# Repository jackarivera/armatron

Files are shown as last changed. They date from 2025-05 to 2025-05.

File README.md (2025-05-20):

# Armatron 7-DOF Robot Arm

## Project Overview
Armatron is an open-source 7-degree-of-freedom robotic arm project that combines hardware, software, and web-based control. This repository contains all the necessary files to build, program, and control your own Armatron robot arm.

## Repository Structure
```
.
├── armatron_software/     # Software implementation
│   ├── controls/         # C++ control system
│   ├── web/             # Web interface
├── CAD Files/           # CAD models and drawings
└── resources/           # Additional resources
```

## Hardware Requirements

### Electronics
- BeagleBone Black (BBB)
- 7x Fully Integrated BLDC Motors
- Armatron Electronics System (See BOM and Electronics CAD)

### Mechanical Parts
- 3D Printed Components (STL files and Fusion360 Project Provided)
- Bearings
- Fasteners
- Timing Belts

## Software Requirements
- WSL2 with Ubuntu (recommended)
- Python 3.x
- Node.js
- Git
- CMake
- Cross-compilation toolchain

## Getting Started

### 1. Hardware Assembly
1. Download the CAD files / Fusion 360 Project from the CAD files directory
2. Familiarize yourself with the mechanical structure of the project
3. Print or manufacture the structural pieces within the project (Recommended 3D Print Material: PA12 Nylon CF [Bambulabs PAHT-CF or similar])
4. Assemble mechanical pieces
5. Wire the motors. This is left up to you how you want to wire it. When I built armatron, I hand soldered a long wiring harness using the electrical raceway design I provided. This was extremely taxing and I recommend brainstorming new wiring methods that make it easier to assemble.

### 2. Software Setup
1. Clone this repository
2. Navigate to the software directory
3. Run the setup script:
   ```bash
   ./setup_dev.sh
   ```
4. The setup script should ideally set up everything for cross compilation and remote development. I recommend using WSL2 or a linux machine for this. This script is specifically for developing remotely and cross compiling with deployments. You can of course also just build both the C++ project and Web dashboard on whatever control computer you are using instead. I leave this up to you to decide.

### 3. Deployment - if remotely deploying
1. Configure your BBB's IP and credentials in the setup files
2. Run the deployment script:
   ```bash
   sudo ./deploy.sh
   ```

## CAD Files
The `CAD Files` directory contains:
- Complete Fusion 360 project file
- Individual component files in multiple formats - These aren't organized that great so I recommend pulling new STL files from the fusion project

## Disclaimer
While this project has been built up to an actual product that functions correctly and has a lot of potential, it does lack comprehensive documentation, assembly guides, and troubleshooting tips. I do apologize for this, however, I completed this project in my final semester of college at Purdue University. I am now transitioning into a full time position at SpaceX and do not have nearly enough time to smooth the rough edges of this project. I am releasing this fully open source to ensure that individuals, universities, and even companys have access to high performance robotics at an affordable cost. I welcome all contributors and am seeking people to help keep this project alive and prospering! If you are interested- please email me directly and we can set up a time to chat. Alternatively, if you are feeling ambitious, the best way to understand this project is to just dive in. Read the code, view the CAD, and gain a deep understanding of what I have set up so far. I believe the best engineers are made by working through the tough projects that have minimal documentation. While I would prefer to provide step-by-step manufacturing, assembly, and software documentation and tutorials- I just don't have the time right now to provide this. I apologize for this but I believe with the right support, this project can take off and help eager students and engineers around the world a great starting point for creating something awesome!

## Known bugs at release (IMPORTANT)-
Please note that this project is not free of bugs and ignoring some bugs or blindly running the software provided with this project can lead to catastrophic failures. The actuators used in this project are POWERFUL. Please proceed with extreme care and DO NOT ASSUME that everything will work out of the box.

Here is a list of known bugs at release:
- moveToJointPositon() in C++ controls (robot_interface.cpp)
    - DOES NOT PROPERLY HANDLE INTERUPPTING ACTIVE TRAJECTORIES. A trajectory currently must finish before calling moveToJointPosition again. Alternatively, you can call setHoldPosition to stop the trajectory and then move again. 

## Not implemented features yet
- Forward or Inverse Kinematics
- Cartesian Space Trajectory controls
- Dynamics Controls
- Open endpoints for trajectory streaming
- ROS2 Project
- Full URDF implementation - A partial implementation exists for the web visualization though. See the web/public/models directory

## Contributing
We welcome contributions! If you are interested in contributing to this project please contact me directly or open a pull request! I am currently working with Rover Robotics (https://roverrobotics.com/) to help continue supporting this project.

## License
This project uses a slightly modified MIT license. The only modifications go to include ALL files included in this repository including CAD, BOM, Documentation, etc instead of just software.

## Support
- Create an issue in the repository
- Join our community forum (link to be added)

## Acknowledgments
- Created by Jack Rivera as a passion project during my final semester at Purdue University. Shoutout Professor Hyun, Professor Sundaram, and Professor Pare for inspiring me and supporting throughout the development.

- Special thanks to...
- Inspired by...

## Roadmap
- [ ] Add detailed manufacturing instructions
- [ ] Add detailed assembly instructions
- [ ] Add detailed software development instructions
- [ ] Create video tutorials
- [ ] Expand simulation capabilities
- [ ] Implement additional control modes (Kinematics, Dynamics, Cartesian Space, Energy Based, State Space, etc.)
- [ ] Add support for different end effectors 
- [ ] Expand web dashboard
- [ ] Add ROS2 support

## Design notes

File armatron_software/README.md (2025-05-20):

# Armatron 7-DOF Robot Arm Software

## Project Overview
Armatron is a 7-degree-of-freedom robotic arm project, featuring a web-based control interface and real-time control system. The robot is controlled via a BeagleBone Black (BBB) running Debian Linux, providing a robust and flexible platform for robotics development.

### Key Features
- 7-DOF robotic arm control
- Real-time control daemon
- Web-based user interface
- Cross-compilation support for ARM architecture
- Automated deployment system
- Systemd service management

## Project Structure
```
armatron_software/
├── controls/                 # C++ control system
│   ├── src/                 # Source files
│   ├── include/             # Header files
│   └── build/               # Build directory
├── web/                     # Web interface
│   ├── public/              # Static files
│   ├── src/                 # Source files
│   └── node_modules/        # Node.js dependencies
├── deploy/                  # Deployment files
├── setup_dev.sh            # Development environment setup
├── deploy.sh               # Deployment script
└── toolchain.cmake         # CMake toolchain configuration
```

## Development Environment Setup

### Prerequisites
- WSL2 with Ubuntu (recommended)
- Python 3.x
- Node.js
- Git
- CMake
- Cross-compilation toolchain

### Initial Setup
1. Clone the repository:
```bash
git clone <repository-url>
cd armatron_software
```

2. Run the setup script:
```bash
./setup_dev.sh
```

This will:
- Install required packages
- Set up cross-compilation toolchain
- Create Python virtual environment
- Generate deployment scripts
- Configure CMake toolchain

### Configuration
Edit the following files to set your BBB's IP and credentials:
1. `setup_dev.sh`
2. `deploy.sh`

## Deployment

### Regular Deployment
For normal development and updates:
```bash
sudo ./deploy.sh
```

This will:
- Build the project
- Deploy files to BBB
- Preserve node_modules
- Restart services

### Initial Setup on BBB
For first-time setup or when BBB environment needs reinitialization:
```bash
sudo ./deploy.sh --setup
```

This will:
- Run all regular deployment steps
- Execute setup_bbb.sh on the BBB
- Install system dependencies

### Node Modules Management
Node modules are automatically checked and only installed if missing or invalid. No need to manually manage them.

## Service Management
The system uses two systemd services:
- `armatron-control`: Real-time control daemon
- `armatron-web`: Web interface server

Services are automatically managed during deployment.

## Development Workflow
1. Make changes to source code
2. Run `sudo ./deploy.sh`
3. Changes are automatically deployed and services are restarted

## Troubleshooting
- If services fail to start, check the logs:
  ```bash
  sudo journalctl -u armatron-control
  sudo journalctl -u armatron-web
  ```
- If node modules are missing, the deployment script will automatically install them
- For permission issues, ensure you're running the deploy script with sudo

## Notes
- The deployment script preserves node_modules to speed up deployments
- Sudo password is automatically handled for BBB commands
- The web interface communicates with the control daemon via Unix domain socket
- Cross-compilation is configured for ARM architecture

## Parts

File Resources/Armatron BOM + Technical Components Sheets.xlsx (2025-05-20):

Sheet: BOM (Motors)
Armatron 7 BOM
Total Cost (Pre-tax and Fees): $1501.20
Item # | Description | Vendor | Part Number | Qty | Cost | Link to Where to Purchase | AliExpress
1 | MG8015-9 Duo 2 V2 - 14-28Nm 177RPM | smc-powers | MG8015-9 | 2 | $263.00 | MG8015-9 (http://shop.smc-powers.com/MG8015-9-Duo-CAN.html) | MG8015E-i9 (https://www.aliexpress.us/item/3256807777004232.html)
2 | MG8008-9 Duo V3 - 10-20Nm 178RPM | smc-powers | MG8008-9 | 2 | $237.80 | MG8008-9 (http://shop.smc-powers.com/MG8008-9-Duo-CAN.html) | MG8016-i6v2 (https://www.alibaba.com/product-detail/MG8016-i6v2-RMD-X8-Brushless-bldc_1600372824820.html)
3 | MG4010-10 Duo V3 - 2.5-4.5Nm 260RPM | smc-powers | MG4010-10 | 1 | $168.00 | MG4010-10 (http://shop.smc-powers.com/MG4010-10-Duo-CAN.html)
4 | MG4005-10 - 1-2.5Nm 253RPM | smc-powers | MG4005-10 | 2 | $165.80 | MG4005-10 (http://shop.smc-powers.com/MG4005-Motor-CAN)

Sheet: BOM (Controls + Electronics Enc
Armatron 7 BOM
Total Cost: $987.77
Item # | Description | Vendor | Part Number | Qty | Cost | Link to Where to Purchase | AliExpress
1 | Beaglebone Black | Digikey | RPI5 | 1 | $53.77 | Digikey - BBB (https://www.digikey.com/en/products/detail/beagleboard-by-seeed-studio/102110420/12719590)
2 | Beaglebone Power Cape | Digikey | PWRCPE | 1 | $40.00 | Digikey - PWRCPE (https://www.digikey.com/en/products/detail/ghi-electronics-llc/PWRCPE-BBBCAPE/8567321)
3 | Beaglebone Comms Cape | Digikey | COMCPE | 1 | $40.00 | Digikey - COMCPE (https://www.digikey.com/en/products/detail/ghi-electronics-llc/COMCPE-BBBCAPE/8567318)
4 | Meanwell RSP-2000w-48v Power Supply | Digikey | RSP-2000-48 | 1 | $500.00 | Digikey - MWRSP (https://www.digikey.com/en/products/detail/mean-well-usa-inc/RSP-2000-48/7706318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)
5 | Meanwell 24v Power Supply - 24V 15A 360W | Owned (24v 15A Meanwell) | LRS-350-24 | 1 | $0.00 | Digikey - MWLRS (https://www.digikey.com/en/products/detail/mean-well-usa-inc/LRS-350-24/7705034)
6 | 10A 1P Circuit Breaker | RS | 2907566 | 1 | $20.00 | https://us.rs-online.com/product/phoenix-contact/2907566/70903605/
7 | 20A 1P Circuit Breaker | RS | 2907573 | 1 | $20.00 | https://us.rs-online.com/product/phoenix-contact/2907573/70903610/
8 | MakerBeam XL Kit | Amazon | MakerBeamXL | 1 | $200.00 | https://www.amazon.com/MakerBeam-XL-anodized-including-brackets/dp/B06XHXJSVL
9 | Parallel XT90s | Amazon | LINSYRC | 2 | $9.00 | https://www.amazon.com/LinsyRC-Parallel-Connector-Quadcopters-Multirotors/dp/B093GL6TPW
10 | XT90s Male + Females | Amazon | AMASS | 2 | $13.00 | https://www.amazon.com/XT90-S-Connector-Anti-Spark-Battery-Charger/dp/B08P5N29RK
 | Terminal Blocks Below
11 | Phoenix Contact 3212934 Feed-througterm block Push-in conn AWG:20-8 W:8.2mm 42.2mm gray NS35/7 5 NS35/15 | RS | 3212934 | 6 | $6.00 | https://us.rs-online.com/product/phoenix-contact/3212934/70925206/?referrer=search
12 | Phoenix Contact 3212950 Terminal Block Ground Modular Push-In PT 6-QUATTRO-PE PT Series | RS | 3212950 | 2 | $12.00 | https://us.rs-online.com/product/phoenix-contact/3212950/70378433/?keyword=3212950
13 | Phoenix Contact End Cover PT 6-QUATTRO | RS | 3212963 | 2 | $1.00 | https://us.rs-online.com/product/phoenix-contact/3212963/70254907/?referrer=search
14 | Phoenix Contact End Stop Din Rail | RS | 800886 | 4 | $2.00 | https://us.rs-online.com/product/phoenix-contact/0800886/70169101/?referrer=search
15
16
17
18
19
20
21
22
23
24
25
26
27
28
29
30
31
32
33
34
35
36
37
38
39
40
41
42
43
44
45
46
47
48
49
50
51
52
53
54
55
56
57

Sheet: BOM (Hardware)
Armatron 7 BOM
Total Cost: $44.50
Item # | Description | Vendor | Part Number | Qty | Cost | Link to Where to Purchase
1 | 6656K196 - Ultra Thin Ball Bearing (SHOULDER BEARING) | McMaster | 6656K196 | 1 | $10.74 | 6656K196 (https://www.mcmaster.com/6656K196/)
2 | 6656K201 - Ultra Thin Ball Bearing (WRIST BEARINGS) | McMaster | 6656K201 | 2 | $16.88 | 6656K201 (https://www.mcmaster.com/catalog/131/1431/6656K201)
3 | RS_12-8-3.5_747-800 (Differential Pignon Bearings) |  |  | 4
4 | 123R_14-8-4_SMR148_2RS_ZEN (Differential Main Axle Bearings) |  |  | 2
5 | Xl Series Timing Belt, Trade No. 140xl025 (https://www.mcmaster.com/catalog/6484K124)
 | Timing Belt, Xl Series, Trade Number 96xl025, 1/4" Wide (https://www.mcmaster.com/catalog/6484K2)

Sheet: Motor Torque Comparison
Item # | Description | Type | Vendor | Part Number | Rated Torque (Nm) | Max Torque (Nm) | 2:1 Gearbox | 2:1 Gearbox
1 | MG8015-9 Duo 2 V2 - 14-28Nm 177RPM | Motor | smc-powers | MG8015-9 | 14.00 | 28.00 | N/A | N/A
2 | MG8008-9 Duo V3 - 10-20Nm 178RPM | Motor | smc-powers | MG8008-9 | 10.00 | 20.00 | N/A | N/A
3 | MG4010-10 Duo V3 - 2.5-4.5Nm 260RPM | Motor | smc-powers | MG4010-10 | 2.50 | 4.50 | 5 | 9
4 | MG4005-10 - 1-2.5Nm 253RPM | Motor | smc-powers | MG4005-10 | 1.00 | 2.50 | 2 | 5

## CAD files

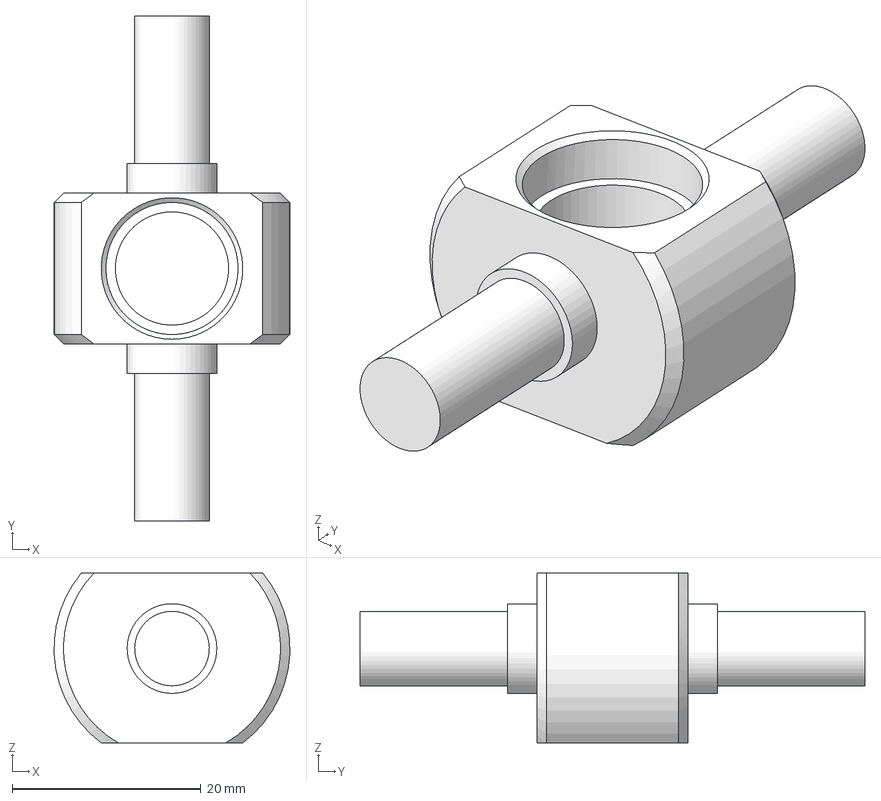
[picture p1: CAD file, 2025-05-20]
CAD Files/Differential Prints/main_axle.step
25.0 x 53.5 x 18.0 mm

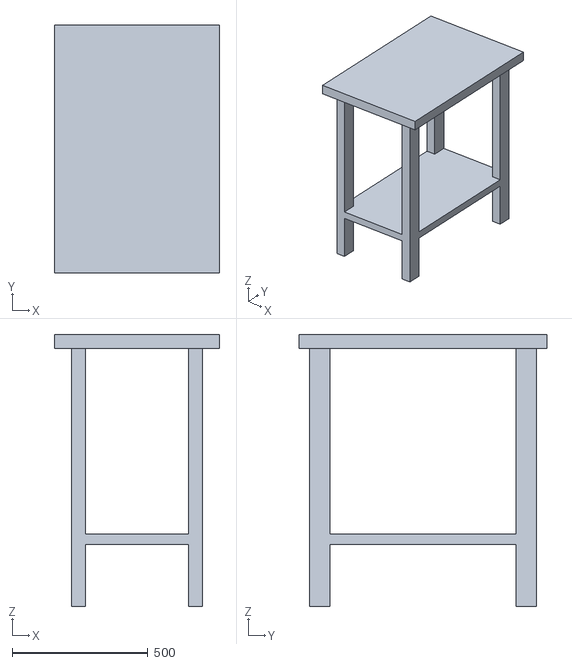
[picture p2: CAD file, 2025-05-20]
armatron_software/web/dist/models/urdf/meshes/demo_table.stl
609.6 x 914.4 x 1003.3

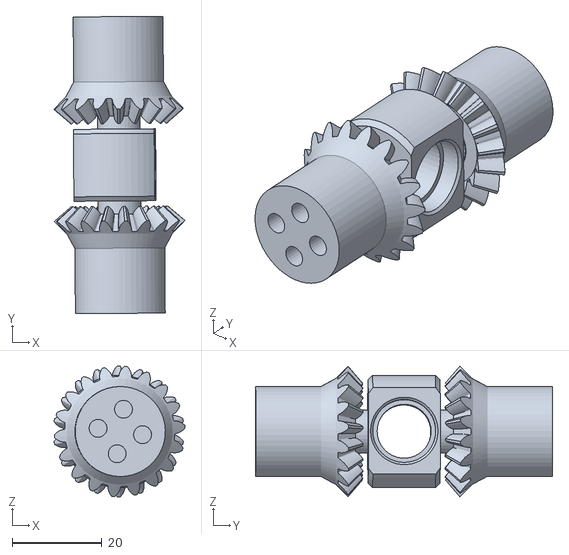
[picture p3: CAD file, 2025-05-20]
armatron_software/web/public/models/urdf/meshes/7_diff_crossbar_link.stl
29.1 x 66.2 x 29.1

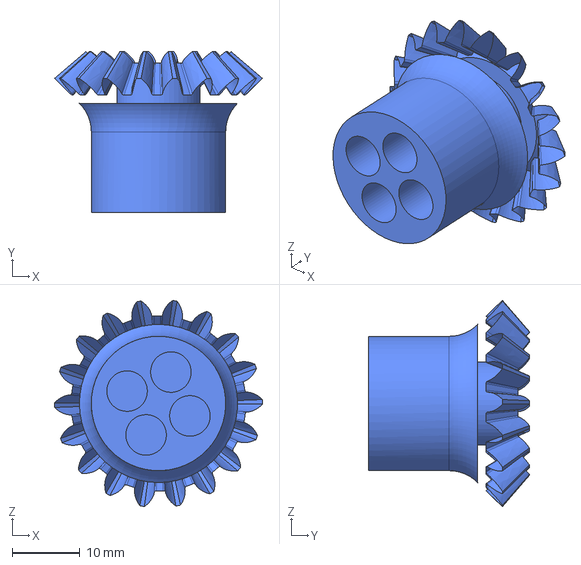
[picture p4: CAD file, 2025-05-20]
CAD Files/Differential Prints/pignon_ab.step
30.8 x 23.8 x 30.5 mm

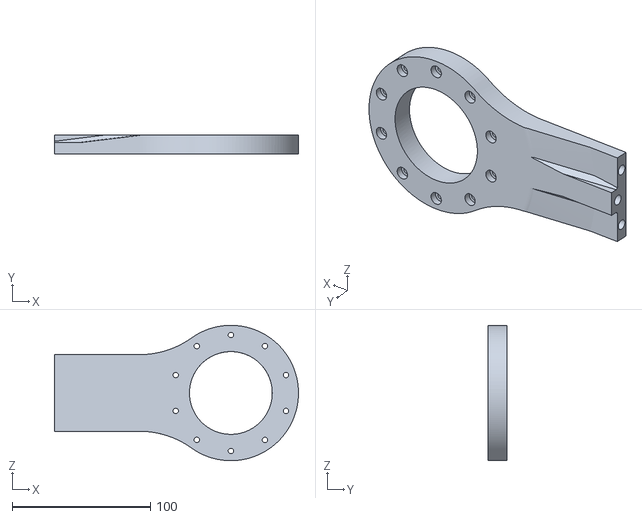
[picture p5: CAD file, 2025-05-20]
CAD Files/Elbow Prints/armatron_7 v125.stl
176.8 x 13.5 x 98.1

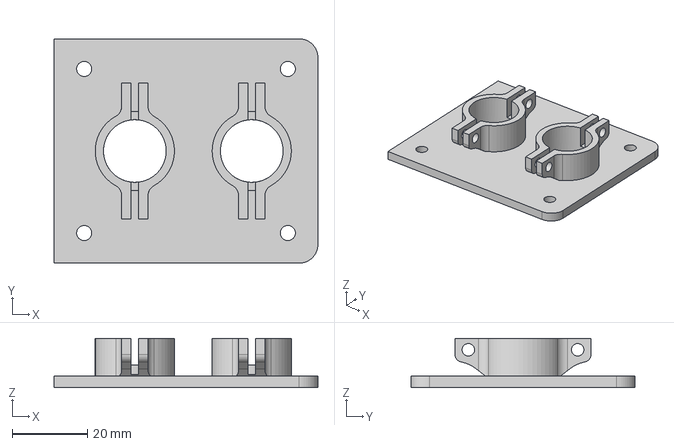
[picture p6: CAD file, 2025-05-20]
CAD Files/Electrical Raceway Prints/armatron_7 v181.step
70.0 x 59.5 x 13.0 mm

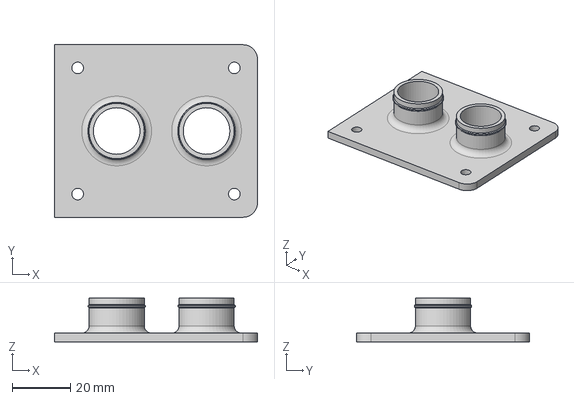
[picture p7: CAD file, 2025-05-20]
CAD Files/Electrical Raceway Prints/Joint 1/Joint_1_Lid.step
70.0 x 59.5 x 15.0 mm

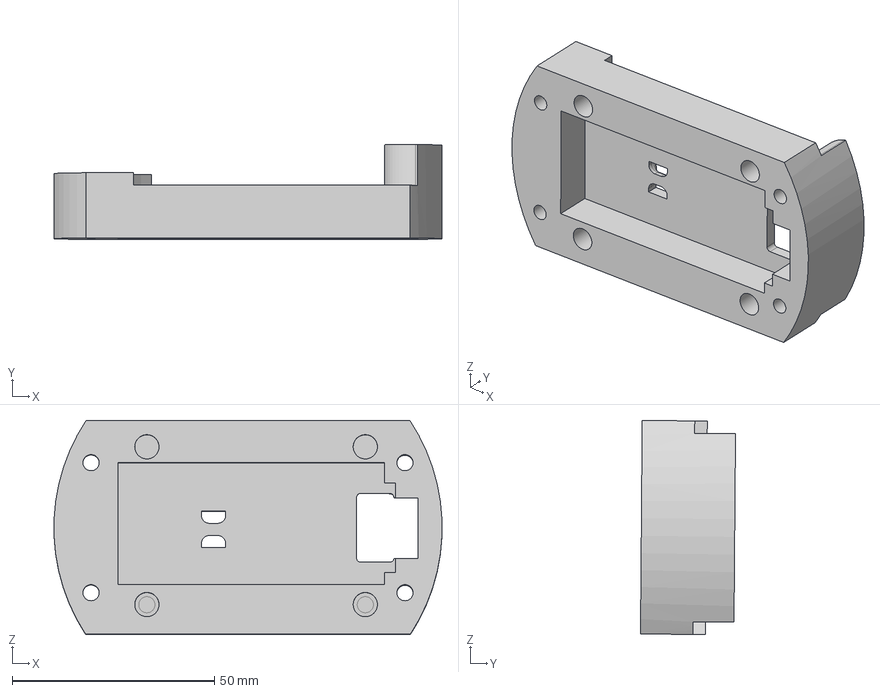
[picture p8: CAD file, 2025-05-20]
CAD Files/Electrical Raceway Prints/Joint 2/Joint_2_Base.step
95.9 x 23.5 x 52.9 mm

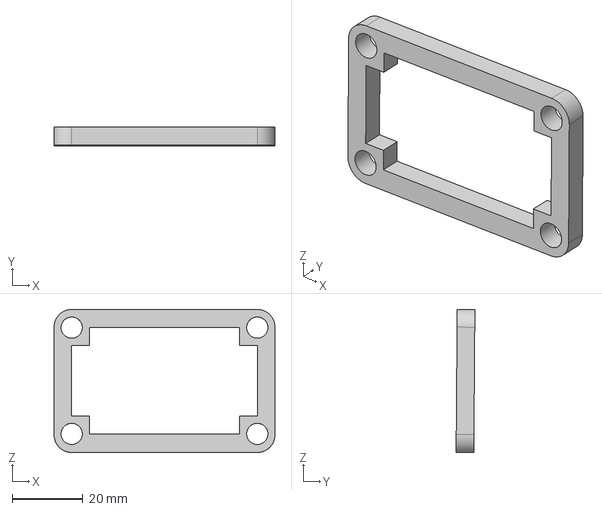
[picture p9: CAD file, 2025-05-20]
CAD Files/Electrical Raceway Prints/Joint 3/Joint_3_Spacer.step
62.4 x 5.32 x 40.4 mm

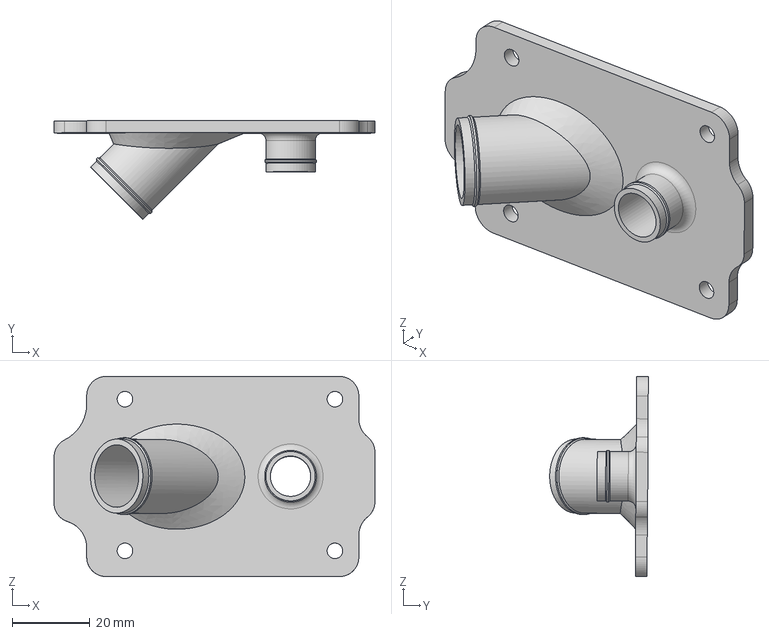
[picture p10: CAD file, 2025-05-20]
CAD Files/Electrical Raceway Prints/Joint 4/Joint_4_lid.step
82.6 x 25.4 x 51.5 mm

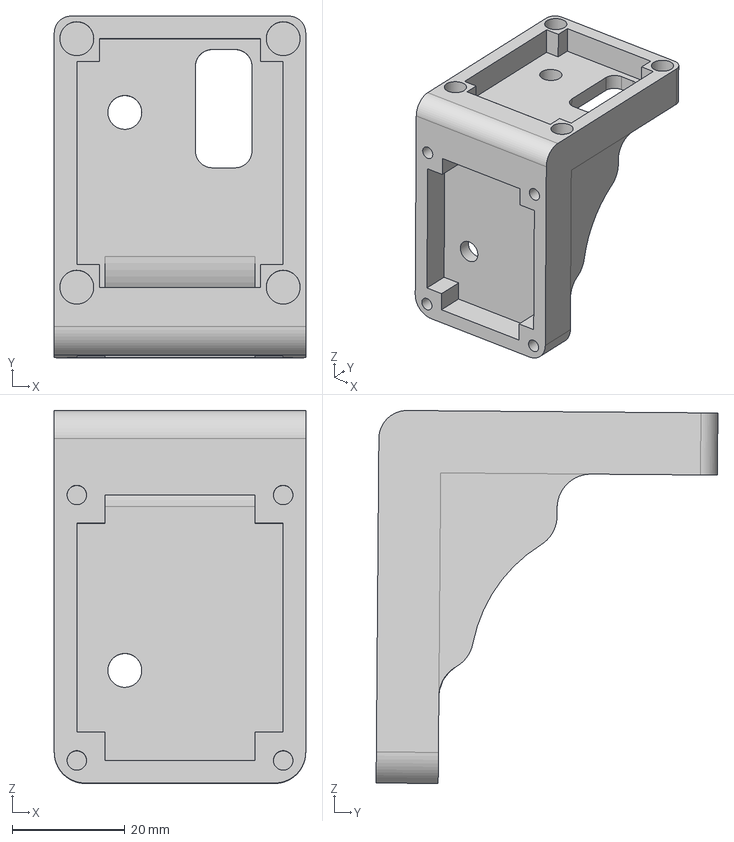
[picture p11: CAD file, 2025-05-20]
CAD Files/Electrical Raceway Prints/Joint 5/joint_5_base.step
44.5 x 60.5 x 66.0 mm

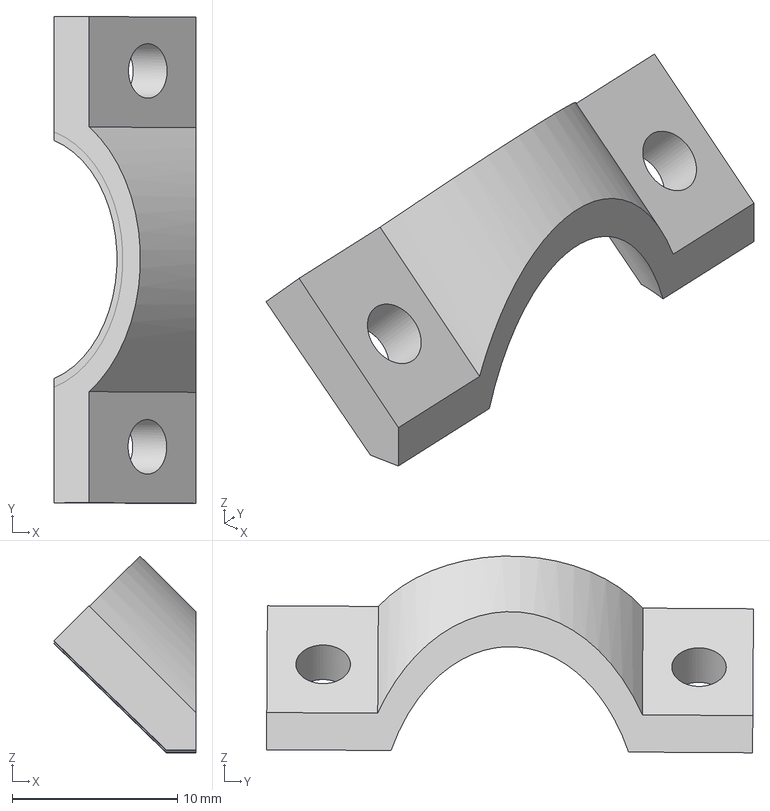
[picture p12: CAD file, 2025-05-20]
CAD Files/Electrical Raceway Prints/Joint 6/diff_clamp.step
8.58 x 29.5 x 11.9 mm

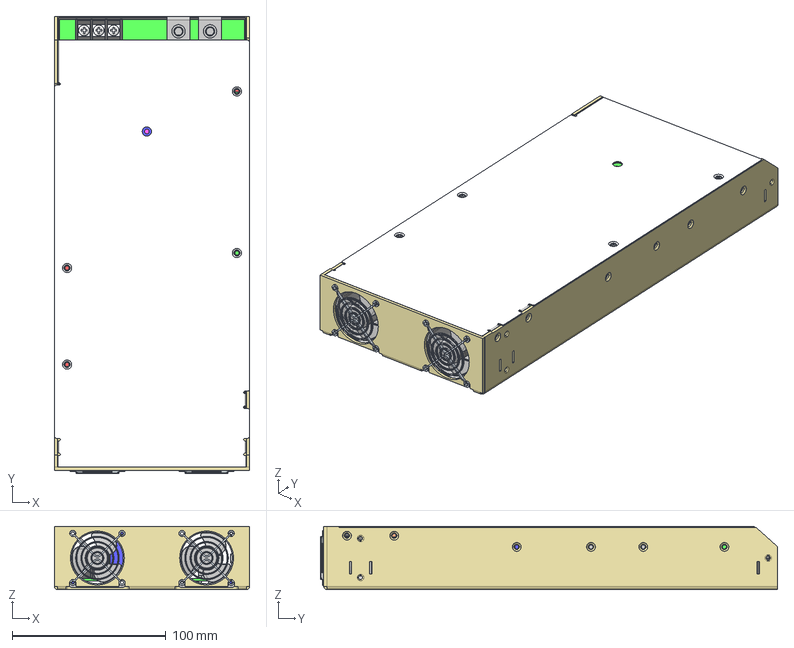
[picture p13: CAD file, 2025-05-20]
CAD Files/Electronics CAD/RSP-2000..stp
127.0 x 297.1 x 41.0 mm
nt x 4
p3.1 x 2
ºÝ¤l
pcb2
M3
VR.1
FAN x 4
fan_a x 4
pin.1 x 6
p3 x 2
pin
hs123
ff.1.1.1.1.1 x 3
CASE
M3-10LÁ³¬W.1.1.1.1.3 x 5
PCB-2
ºÝ¤l®y¤½W
MOS15.5x10.1.1.1.1.1.1.1.1.1.1.1.1.1 x 18
©T©w¤ù1 x 3
HHJ x 2
cu2
mylr
952¤W»\
pcb
HS3
p1.2 x 2

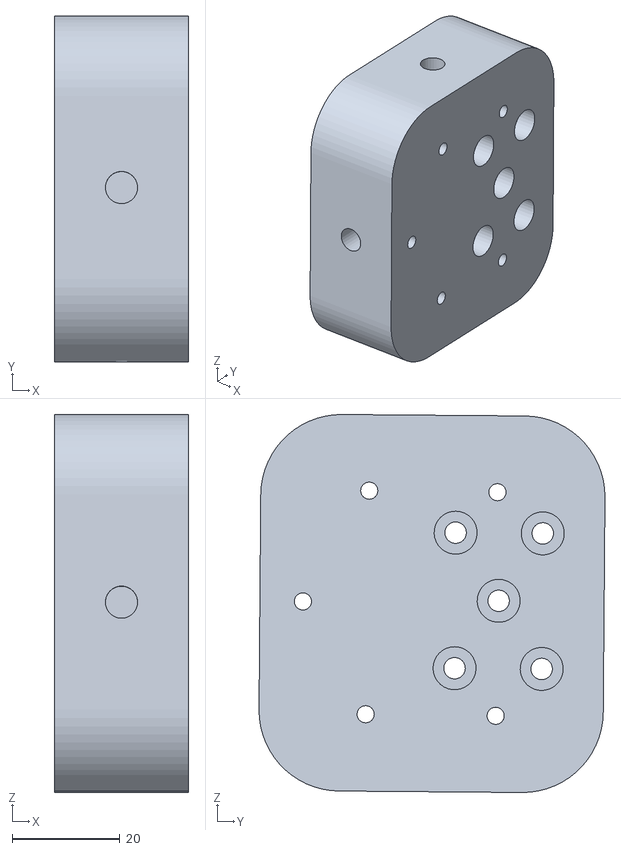
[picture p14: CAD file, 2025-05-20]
CAD Files/Forearm Prints/arm_to_motor_p1_nylon_toleranced.stl
25.0 x 64.3 x 70.3

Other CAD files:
CAD Files/Shoulder Prints/shoulder_faceplate.step
CAD Files/Test Mounts/force_gauge_mount.3mf
CAD Files/torque_test_stand v1 Bambu.3mf
CAD Files/Wrist Prints/divider.step
CAD Files/Differential Prints/pulley_diff.step
CAD Files/Elbow Prints/base_stand_p1_nylon.3mf
CAD Files/Elbow Prints/elbow_bambu_project.3mf
CAD Files/Elbow Prints/mount_p1_nylon_toleranced.stl
CAD Files/Electrical Raceway Prints/Joint 1/Joint_1_Base.step
CAD Files/Electrical Raceway Prints/Joint 1/Joint_1_Spacer.step
CAD Files/Electrical Raceway Prints/Joint 2/Joint_2_Clamp.step
CAD Files/Electrical Raceway Prints/Joint 2/Joint_2_Lid.step
CAD Files/Electrical Raceway Prints/Joint 2/Joint_2_Spacer.step
CAD Files/Electrical Raceway Prints/Joint 3/Joint_3_Base.step
CAD Files/Electrical Raceway Prints/Joint 3/Joint_3_Lid.step
CAD Files/Electrical Raceway Prints/Joint 3/Joint_3_clamp.step
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

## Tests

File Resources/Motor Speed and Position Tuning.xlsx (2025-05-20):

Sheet: MG8015 | Joint 1
Lever Arm Length | 0.047205
Torque Current Value (-2048-2048) | Force #1 | Force #2 | Force #3 | Avg Force (N) | Avg Torque (Nm) | Expected Torque (Nm)
50 | 24 | 23 | 23.2 | 23.4 | 1.104597 | 1.2
75 | 34.7 | 36 | 36.7 | 35.8 | 1.689939 | 1.705
100 | 48.8 | 48.6 | 48.8 | 48.73333333 | 2.300457 | 2.21
125 | 56.8 | 56.2 | 61.4 | 58.13333333 | 2.744184 | 2.715
150 | 67 | 68.5 | 68.7 | 68.06666667 | 3.213087 | 3.22
175 | 80 | 80.5 | 79.9 | 80.13333333 | 3.782694 | 3.725
200 | 89 | 90 | 89.7 | 89.56666667 | 4.2279945 | 4.23
225 | 98 | 98.6 |  | 98.3 | 4.6402515 | 4.735
250 |  |  |  | #DIV/0! | #DIV/0! | 5.24
275 |  |  |  | #DIV/0! | #DIV/0! | 5.745
300 |  |  |  | #DIV/0! | #DIV/0! | 6.25
325 |  |  |  | #DIV/0! | #DIV/0! | 6.755
350 |  |  |  | #DIV/0! | #DIV/0! | 7.26
375 |  |  |  | #DIV/0! | #DIV/0! | 7.765
400 |  |  |  | #DIV/0! | #DIV/0! | 8.27
425 |  |  |  | #DIV/0! | #DIV/0! | 8.775
450 |  |  |  | #DIV/0! | #DIV/0! | 9.28
475 |  |  |  | #DIV/0! | #DIV/0! | 9.785
500 |  |  |  | #DIV/0! | #DIV/0! | 10.29
525 |  |  |  |  |  | 10.795
550 |  |  |  |  |  | 11.3
575 |  |  |  |  |  | 11.805
600 |  |  |  |  |  | 12.31
625 |  |  |  |  |  | 12.815
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

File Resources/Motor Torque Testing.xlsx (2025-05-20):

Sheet: MG8015 | Joint 1
Lever Arm Length | 0.047205
Torque Current Value (-2048-2048) | Force #1 | Force #2 | Force #3 | Avg Force (N) | Avg Torque (Nm) | Expected Torque (Nm)
50 | 24 | 23 | 23.2 | 23.4 | 1.104597 | 1.2
75 | 34.7 | 36 | 36.7 | 35.8 | 1.689939 | 1.705
100 | 48.8 | 48.6 | 48.8 | 48.73333333 | 2.300457 | 2.21
125 | 56.8 | 56.2 | 61.4 | 58.13333333 | 2.744184 | 2.715
150 | 67 | 68.5 | 68.7 | 68.06666667 | 3.213087 | 3.22
175 | 80 | 80.5 | 79.9 | 80.13333333 | 3.782694 | 3.725
200 | 89 | 90 | 89.7 | 89.56666667 | 4.2279945 | 4.23
225 | 98 | 98.6 |  | 98.3 | 4.6402515 | 4.735
250 |  |  |  | #DIV/0! | #DIV/0! | 5.24
275 |  |  |  | #DIV/0! | #DIV/0! | 5.745
300 |  |  |  | #DIV/0! | #DIV/0! | 6.25
325 |  |  |  | #DIV/0! | #DIV/0! | 6.755
350 |  |  |  | #DIV/0! | #DIV/0! | 7.26
375 |  |  |  | #DIV/0! | #DIV/0! | 7.765
400 |  |  |  | #DIV/0! | #DIV/0! | 8.27
425 |  |  |  | #DIV/0! | #DIV/0! | 8.775
450 |  |  |  | #DIV/0! | #DIV/0! | 9.28
475 |  |  |  | #DIV/0! | #DIV/0! | 9.785
500 |  |  |  | #DIV/0! | #DIV/0! | 10.29
525 |  |  |  |  |  | 10.795
550 |  |  |  |  |  | 11.3
575 |  |  |  |  |  | 11.805
600 |  |  |  |  |  | 12.31
625 |  |  |  |  |  | 12.815
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

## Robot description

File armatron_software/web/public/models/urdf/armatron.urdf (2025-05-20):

<?xml version="1.0"?>
<robot name="my_robot" xmlns:xacro="http://ros.org/wiki/xacro">

  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
  <link name="world">
    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
  </link>
  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
  <link name="demo_table">
    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
    <inertial>
      <origin xyz="0 0 0" rpy="0 0 0"/>
      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
      <mass value="1.0"/>
      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
    </inertial>
  </link>

  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
  <link name="1_base_link">
    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
    <inertial>
      <origin xyz="0 0 0" rpy="0 0 0"/>
      <mass value="1.0"/>
      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
    </inertial>
  </link>

  <joint name="demo_table_to_1_base" type="fixed">
    <parent link="demo_table"/>
    <child link="1_base_link"/>
    <origin xyz="0 0 0" rpy="0 0 0"/>
  </joint>

  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
  <link name="2_shoulder_link">
    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
    <inertial>
      <origin xyz="0 0 0" rpy="0 0 0"/>
      <mass value="1.0"/>
      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
    </inertial>
  </link>

  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
  <link name="3_upper_brachium_link">
    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
    <inertial>
      <origin xyz="0 0 0" rpy="0 0 0"/>
      <mass value="1.0"/>
      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
    </inertial>
  </link>

  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
  <link name="4_lower_brachium_link">
    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
    <inertial>
      <origin xyz="0 0 0" rpy="0 0 0"/>
      <mass value="1.0"/>
      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
    </inertial>
  </link>

  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
  <link name="5_upper_forearm_link">
    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
    <inertial>
      <origin xyz="0 0 0" rpy="0 0 0"/>
      <mass value="1.0"/>
      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
    </inertial>
  </link>

  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
  <link name="6_lower_forearm_link">
    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
    <inertial>
      <origin xyz="0 0 0" rpy="0 0 0"/>
      <mass value="1.0"/>
      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
    </inertial>
  </link>

  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
  <link name="7_diff_crossbar_link">
    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
    <inertial>
      <origin xyz="0 0 0" rpy="0 0 0"/>
      <mass value="1.0"/>
      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
    </inertial>
  </link>

  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
  <link name="8_diff_tool_link">
    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
    <inertial>
      <origin xyz="0 0 0" rpy="0 0 0"/>
      <mass value="1.0"/>
      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
    </inertial>
  </link>

  

  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

  <joint name="J1" type="revolute">
    <parent link="1_base_link"/>
    <child link="2_shoulder_link"/>
    <origin xyz="0 0 0.093107" rpy="0 0 1.855285"/>
    <axis xyz="0 0 -1"/>
    <limit lower="-6.28319" upper="6.28319" effort="1000" velocity="0.5"/>
  </joint>

  <joint name="J2" type="revolute">
    <parent link="2_shoulder_link"/>
    <child link="3_upper_brachium_link"/>
    <origin xyz="0 -0.0049910 0.06826" rpy="0 0.3494533 0"/>
    <axis xyz="0 -1 0"/>
    <limit lower="-6.28319" upper="6.28319" effort="1000" velocity="0.5"/>
  </joint>

  <joint name="J3" type="revolute">
    <parent link="3_upper_brachium_link"/>
    <child link="4_lower_brachium_link"/>
    <origin xyz="0.148 0.0075 0" rpy="1.514946 0 0"/>
    <axis xyz="-1 0 0"/>
    <limit lower="-6.28319" upper="6.28319" effort="1000" velocity="0.5"/>
  </joint>

  <joint name="J4" type="revolute">
    <parent link="4_lower_brachium_link"/>
    <child link="5_upper_forearm_link"/>
    <origin xyz="0.137793 -0.00150 0" rpy="0 2.3423599 0"/>
    <axis xyz="0 -1 0"/>
    <limit lower="-6.28319" upper="6.28319" effort="1000" velocity="0.5"/>
  </joint>

  <joint name="J5" type="revolute">
    <parent link="5_upper_forearm_link"/>
    <child link="6_lower_forearm_link"/>
    <origin xyz="0.133686 0.000111 0" rpy="-1.5573573 0 0"/>
    <axis xyz="1 0 0"/>
    <limit lower="-6.28319" upper="6.28319" effort="1000" velocity="0.5"/>
  </joint>

  <joint name="J6" type="revolute">
    <parent link="6_lower_forearm_link"/>
    <child link="7_diff_crossbar_link"/>
    <origin xyz="0.17835 0 0" rpy="0 0 0"/>
    <axis xyz="0 1 0"/>
    <limit lower="-6.28319" upper="6.28319" effort="1000" velocity="0.5"/>
  </joint>

  <joint name="J7" type="revolute">
    <parent link="7_diff_crossbar_link"/>
    <child link="8_diff_tool_link"/>
    <origin xyz="0.0455 0 0" rpy="0 0 0"/>
    <axis xyz="1 0 0"/>
    <limit lower="-6.28319" upper="6.28319" effort="1000" velocity="0.5"/>
  </joint>

</robot>

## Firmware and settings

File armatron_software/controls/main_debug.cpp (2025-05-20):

#include "can_handler.hpp"
#include "motor_interface.hpp"
#include "robot_interface.hpp"
#include <iostream>
#include <chrono>
#include <thread>

int main()
{
    try {
        // 1) Bring up can0 externally: 
        //    sudo ip link set can0 type can bitrate 1000000
        //    sudo ip link set can0 up

        // 2) Create CAN interface
        std::cerr << "Before creating CANHandler...\n";
        CANHandler can("can0");
        std::cerr << "After creating CANHandler.\n";

        // 3) Create a RobotInterface for 7 motors
        std::cerr << "Before creating robot...\n";
        RobotInterface robot(can);
        std::cerr << "After creating robot...\n";

        // 4) Let's just test motor #1 for now
        std::cerr << "Before getMotor...\n";
        auto& motor1 = robot.getMotor(1);
        std::cerr << "After getMotor...\n";

        // Turn motor on
        std::cerr << "Before motorOn...\n";
        motor1.motorOn();
        std::cerr << "After motorOn...\n";

        // Wait a moment
        //std::this_thread::sleep_for(std::chrono::milliseconds(200));

        // Possibly do a torque command 
        // Let's set torque = 500 in raw units => ~ ~4A 
        // motor1.setTorque(500);

        // Read the state to see if we got a response
        while(true){
        motor1.readState2();
        const auto st = motor1.getState();

        std::cerr << "[Main] Motor1 => Temp=" << st.temperatureC 
                  << "C, TorqueCurrent=" << st.torqueCurrentA
                  << "A, Speed=" << st.speedDeg_s << " deg/s\n";
        }

        // Turn off
        motor1.motorOff();

        std::cout << "[Main] Done.\n";
    }
    catch(const std::exception &ex) {
        std::cerr << "[Main] Exception: " << ex.what() << std::endl;
        return 1;
    }
    return 0;
}

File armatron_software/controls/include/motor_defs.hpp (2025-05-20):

// // // // // // // // // // // // // // // 
//                                        //
//       Motor Parameter Definitions      //
//                                        //
// // // // // // // // // // // // // // //

// MG8015
#define MG8015_MAX_TORQUE_NM 28
#define MG8015_RATED_TORQUE_NM 14
#define MG8015_REDUCTION_RATIO 9
#define MG8015_SINGLE_TURN_DEG_SCALE_MAX 324

// MG8008
#define MG8008_MAX_TORQUE_NM 20
#define MG8008_RATED_TORQUE_NM 10
#define MG8008_REDUCTION_RATIO 9
#define MG8008_SINGLE_TURN_DEG_SCALE_MAX 324

// MG4010
#define MG4010_MAX_TORQUE_NM 4.5
#define MG4010_RATED_TORQUE_NM 2.5
#define MG4010_REDUCTION_RATIO 10
#define MG4010_SINGLE_TURN_DEG_SCALE_MAX 360

// MG4005
#define MG4005_MAX_TORQUE_NM 2.5
#define MG4005_RATED_TORQUE_NM 1
#define MG4005_REDUCTION_RATIO 1
#define MG4005_SINGLE_TURN_DEG_SCALE_MAX 360

// Per Joint Parameters
#define JOINT_1_ANGLE_LIMIT_LOW 0 // Deg Units
#define JOINT_1_ANGLE_LIMIT_HIGH 210 // Deg Units
#define JOINT_1_NM_TO_IQ_M 0 // [iq/Nm]
#define JOINT_1_NM_TO_IQ_B 0 // [iq]
#define JOINT_1_MAX_SPEED 180 // [deg/s]
#define JOINT_1_MAX_ACCEL 360 // [deg/s^2]
#define JOINT_1_MAX_JERK 1800 // [deg/s^3]

#define JOINT_2_ANGLE_LIMIT_LOW 5
#define JOINT_2_ANGLE_LIMIT_HIGH 215
#define JOINT_2_NM_TO_IQ_M 0 // [iq/Nm]
#define JOINT_2_NM_TO_IQ_B 0 // [iq]
#define JOINT_2_MAX_SPEED 180 // [deg/s]
#define JOINT_2_MAX_ACCEL 360 // [deg/s^2]
#define JOINT_2_MAX_JERK 1800 // [deg/s^3]

#define JOINT_3_ANGLE_LIMIT_LOW -30
#define JOINT_3_ANGLE_LIMIT_HIGH 225
#define JOINT_3_NM_TO_IQ_M 0 // [iq/Nm]
#define JOINT_3_NM_TO_IQ_B 0 // [iq]
#define JOINT_3_MAX_SPEED 180 // [deg/s]
#define JOINT_3_MAX_ACCEL 360 // [deg/s^2]
#define JOINT_3_MAX_JERK 1800 // [deg/s^3]

#define JOINT_4_ANGLE_LIMIT_LOW 2.5
#define JOINT_4_ANGLE_LIMIT_HIGH 245
#define JOINT_4_NM_TO_IQ_M 0 // [iq/Nm]
#define JOINT_4_NM_TO_IQ_B 0 // [iq]
#define JOINT_4_MAX_SPEED 180 // [deg/s]
#define JOINT_4_MAX_ACCEL 360 // [deg/s^2]
#define JOINT_4_MAX_JERK 1800 // [deg/s^3]

#define JOINT_5_ANGLE_LIMIT_LOW -30
#define JOINT_5_ANGLE_LIMIT_HIGH 210
#define JOINT_5_NM_TO_IQ_M 0 // [iq/Nm]
#define JOINT_5_NM_TO_IQ_B 0 // [iq]
#define JOINT_5_MAX_SPEED 180 // [deg/s]
#define JOINT_5_MAX_ACCEL 360 // [deg/s^2]  
#define JOINT_5_MAX_JERK 1800 // [deg/s^3]

#define JOINT_6_ANGLE_LIMIT_LOW -36000
#define JOINT_6_ANGLE_LIMIT_HIGH 36000
#define JOINT_6_NM_TO_IQ_M 0 // [iq/Nm]
#define JOINT_6_NM_TO_IQ_B 0 // [iq]

#define JOINT_7_ANGLE_LIMIT_LOW -36000
#define JOINT_7_ANGLE_LIMIT_HIGH 36000
#define JOINT_7_NM_TO_IQ_M 0 // [iq/Nm]
#define JOINT_7_NM_TO_IQ_B 0 // [iq]    

#define DIFF_MAX_SPEED 360 // [deg/s]
#define DIFF_MAX_ACCEL 720  // [deg/s^2]
#define DIFF_MAX_JERK 3600 // [deg/s^3]

#define DIFF_PITCH_ANGLE_LIMIT_LOW -100
#define DIFF_PITCH_ANGLE_LIMIT_HIGH 90

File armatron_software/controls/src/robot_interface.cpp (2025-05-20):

#include "robot_interface.hpp"
#include "motor_defs.hpp"
#include <stdexcept>
#include <iostream>

RobotInterface::RobotInterface(CANHandler& canRef, const std::string& urdf_path)
{
    // Create 7 motors with IDs 0 through 6 - NOTE THE NEGATIVE 1's NEED TO BE CHANGED TO TORQUE CONSTANTS
    // Joint 1 - MG8015 - Base Shoulder
    m_motors.emplace_back(static_cast<uint8_t>(1), canRef, MG8015_REDUCTION_RATIO, MG8015_SINGLE_TURN_DEG_SCALE_MAX, JOINT_1_NM_TO_IQ_M, JOINT_1_NM_TO_IQ_B, JOINT_1_ANGLE_LIMIT_LOW, JOINT_1_ANGLE_LIMIT_HIGH, JOINT_1_MAX_SPEED, JOINT_1_MAX_ACCEL, JOINT_1_MAX_JERK, false);
    // Joint 2 - MG8015 - Mid Shoulder 
    m_motors.emplace_back(static_cast<uint8_t>(2), canRef, MG8015_REDUCTION_RATIO, MG8015_SINGLE_TURN_DEG_SCALE_MAX, JOINT_2_NM_TO_IQ_M, JOINT_2_NM_TO_IQ_B, JOINT_2_ANGLE_LIMIT_LOW, JOINT_2_ANGLE_LIMIT_HIGH, JOINT_2_MAX_SPEED, JOINT_2_MAX_ACCEL, JOINT_2_MAX_JERK, false);
    // // Joint 3 - MG8008 - Brachium Shoulder
    m_motors.emplace_back(static_cast<uint8_t>(3), canRef, MG8008_REDUCTION_RATIO, MG8008_SINGLE_TURN_DEG_SCALE_MAX, JOINT_3_NM_TO_IQ_M, JOINT_3_NM_TO_IQ_B, JOINT_3_ANGLE_LIMIT_LOW, JOINT_3_ANGLE_LIMIT_HIGH, JOINT_3_MAX_SPEED, JOINT_3_MAX_ACCEL, JOINT_3_MAX_JERK, false);
    // // Joint 4 - MG8008 - Elbow Flexor
    m_motors.emplace_back(static_cast<uint8_t>(4), canRef, MG8008_REDUCTION_RATIO, MG8008_SINGLE_TURN_DEG_SCALE_MAX, JOINT_4_NM_TO_IQ_M, JOINT_4_NM_TO_IQ_B, JOINT_4_ANGLE_LIMIT_LOW, JOINT_4_ANGLE_LIMIT_HIGH, JOINT_4_MAX_SPEED, JOINT_4_MAX_ACCEL, JOINT_4_MAX_JERK, false);
    // // Joint 5 - MG4010 - Forearm Rotator
    m_motors.emplace_back(static_cast<uint8_t>(5), canRef, MG4010_REDUCTION_RATIO, MG4010_SINGLE_TURN_DEG_SCALE_MAX, JOINT_5_NM_TO_IQ_M, JOINT_5_NM_TO_IQ_B, JOINT_5_ANGLE_LIMIT_LOW, JOINT_5_ANGLE_LIMIT_HIGH, JOINT_5_MAX_SPEED, JOINT_5_MAX_ACCEL, JOINT_5_MAX_JERK, false);
    // // Joint 6 - MG4005 - Wrist Differential #1 
    m_motors.emplace_back(static_cast<uint8_t>(6), canRef, MG4005_REDUCTION_RATIO, MG4005_SINGLE_TURN_DEG_SCALE_MAX, JOINT_6_NM_TO_IQ_M, JOINT_6_NM_TO_IQ_B, JOINT_6_ANGLE_LIMIT_LOW, JOINT_6_ANGLE_LIMIT_HIGH, DIFF_MAX_SPEED, DIFF_MAX_ACCEL, DIFF_MAX_JERK, true);
    // // Joint 7 - MG4005 - Wrist Differential #2
    m_motors.emplace_back(static_cast<uint8_t>(7), canRef, MG4005_REDUCTION_RATIO, MG4005_SINGLE_TURN_DEG_SCALE_MAX, JOINT_7_NM_TO_IQ_M, JOINT_7_NM_TO_IQ_B, JOINT_7_ANGLE_LIMIT_LOW, JOINT_7_ANGLE_LIMIT_HIGH, DIFF_MAX_SPEED, DIFF_MAX_ACCEL, DIFF_MAX_JERK, true);

    // Initialize kinematics if URDF path is provided
    if (!urdf_path.empty()) {
        if (!m_kinematics.loadURDF(urdf_path)) {
            std::cerr << "Failed to load URDF file: " << urdf_path << std::endl;
        }
    }
}

Motor& RobotInterface::getMotor(int i)
{
    if (i < 1 || i > (int)m_motors.size()) {
        throw std::out_of_range("Motor index out of range");
    }
    return m_motors[i - 1];
}

// Called from real-time daemon every CONTROL_PERIOD (200Hz default)
void RobotInterface::updateAll()
{
    updateJointStates();
    updateDifferentialMotors();
    updateJointTrajectories();


    // Update Cartesian state if kinematics is initialized
    // if (m_kinematics.getChain().getNrOfJoints() > 0) {
    //     std::array<double, 7> current_joints;
    //     for (size_t i = 0; i < m_motors.size(); ++i) {
    //         current_joints[i] = m_motors[i].getState().multiTurnRad_Mapped;
    //     }
    //     m_kinematics.getForwardKinematics(current_joints, m_state.current_pose);
    // }
}

// Sets joint angles for motors 1 through n - input angles in deg (they are converted to raw units after)
void RobotInterface::setMultiJointAngles(std::vector<float> joint_angles, std::vector<float> joint_speeds) {
    for (int i = 1; i <= joint_angles.size(); i++){
        float ang_target_deg = joint_angles.at(i-1);
        //std::cout << "[RobotInterface] Multi Joint Command Received | Motor: " << i << " | Target (deg): " << ang_target_deg << "\n";
        if ((i <= 5 && ang_target_deg >= 0.0) || (i == 6 || i == 7)) {
            auto &curr_mot = m_motors[i-1];
            float ang_target_raw = joint_angles.at(i-1);
            float maxSpeed = abs(joint_speeds.at(i-1));
            m_motors[i-1].setMultiAngleWithSpeed(static_cast<int32_t>(ang_target_raw), static_cast<uint16_t>(maxSpeed));
            //std::cout << "                 Target Angle Raw: " << ang_target_raw << "\n";
            //std::cout << "                 MaxSpeed: " << maxSpeed << "\n";
        }
    }
}

void RobotInterface::setMultiJointSpeeds(std::vector<float> joint_speeds) {
    for (int i = 1; i <= joint_speeds.size(); i++){
        auto &m = m_motors[i-1];
        float speed_target_deg_s = std::clamp(joint_speeds.at(i-1), 
                                      -m.getMaxSpeed()*m.getMaxSpeedModifier(),
                                      m.getMaxSpeed()*m.getMaxSpeedModifier());
        m_motors[i-1].setSpeed(speed_target_deg_s);
    }
}

void RobotInterface::updateDifferentialMotors() {
    m_state.differential_motors.right_motor_angle_rad = (m_motors[5].getState().multiTurnPosition / 10) * (M_PI / 180);
    m_state.differential_motors.left_motor_angle_rad = (m_motors[6].getState().multiTurnPosition / 10) * (M_PI / 180);
    double left_angle = m_state.differential_motors.left_motor_angle_rad;
    double right_angle = m_state.differential_motors.right_motor_angle_rad;
    
    double roll     = -0.5 * (left_angle + right_angle);
    double rawPitch = 0.5 * (left_angle - right_angle);
    // Wrap pitch to [-π, π]
    double pitch = std::fmod(rawPitch + M_PI, 2*M_PI);
    if (pitch < 0) pitch += 2*M_PI;
    pitch -= M_PI;
    
    m_state.differential_motors.roll_angle_rad = roll;
    m_state.differential_motors.pitch_angle_rad = pitch;
    m_state.differential_motors.roll_angle_deg = roll * (180 / M_PI);
    m_state.differential_motors.pitch_angle_deg = pitch * (180 / M_PI);

}

void RobotInterface::updateTwinDifferentialAnglesRad() {
    double left_angle = (m_state.twin_joint_angles_deg[6] / 10) * (M_PI / 180);
    double right_angle = (m_state.twin_joint_angles_deg[5] / 10) * (M_PI / 180);
    
    double roll     = -0.5 * (left_angle + right_angle);
    double rawPitch = 0.5 * (left_angle - right_angle);
    // Wrap pitch to [-π, π]
    double pitch = std::fmod(rawPitch + M_PI, 2*M_PI);
    if (pitch < 0) pitch += 2*M_PI;
    pitch -= M_PI;
    
    m_state.twin_diff_roll_rad = roll;
    m_state.twin_diff_pitch_rad = pitch;    
}
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

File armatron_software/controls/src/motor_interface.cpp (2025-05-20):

#include "motor_interface.hpp"
#include <stdexcept>
#include <iostream>
#include <cstring>
#include <unistd.h>
#include <cmath>
#include <chrono>
#include <algorithm>

namespace
{
    // Helper to pack a 16-bit into two bytes
    inline void pack16(std::vector<uint8_t>& data, size_t idx, int16_t val)
    {
        data[idx]   = static_cast<uint8_t>( val       & 0xFF );
        data[idx+1] = static_cast<uint8_t>((val >> 8) & 0xFF );
    }
    // Helper to pack a 32-bit into four bytes
    inline void pack32(std::vector<uint8_t>& data, size_t idx, int32_t val)
    {
        data[idx]   = static_cast<uint8_t>( val        & 0xFF );
        data[idx+1] = static_cast<uint8_t>((val >> 8)  & 0xFF );
        data[idx+2] = static_cast<uint8_t>((val >> 16) & 0xFF );
        data[idx+3] = static_cast<uint8_t>((val >> 24) & 0xFF );
    }

    inline int16_t unpack16(const struct can_frame& f, int loIdx)
    {
        return static_cast<int16_t>(
            (static_cast<int16_t>(f.data[loIdx+1]) << 8) |
            f.data[loIdx]
        );
    }

    inline int32_t unpack32(const struct can_frame& f, int loIdx)
    {
        return static_cast<int32_t>(
            (static_cast<int32_t>(f.data[loIdx+3]) << 24) |
            (static_cast<int32_t>(f.data[loIdx+2]) << 16) |
            (static_cast<int32_t>(f.data[loIdx+1]) <<  8) |
            f.data[loIdx]
        );
    }
    inline int64_t unpack64(const struct can_frame& f, int loIdx)
    {
        return static_cast<int64_t>(
            (static_cast<int64_t>(f.data[loIdx + 7]) << 56) |
            (static_cast<int64_t>(f.data[loIdx + 6]) << 48) |
            (static_cast<int64_t>(f.data[loIdx + 5]) << 40) |
            (static_cast<int64_t>(f.data[loIdx + 4]) << 32) |
            (static_cast<int64_t>(f.data[loIdx + 3]) << 24) |
            (static_cast<int64_t>(f.data[loIdx + 2]) << 16) |
            (static_cast<int64_t>(f.data[loIdx + 1]) <<  8) |
                static_cast<int64_t>(f.data[loIdx])
        );
    }


    // Define a constant for 2*pi
    const double TWO_PI = 2.0 * M_PI;

    // Helper conversion functions
    inline double degreesToRadians(double degrees) {
        return degrees * M_PI / 180.0;
    }

    inline double radiansToDegrees(double radians) {
        return radians * 180.0 / M_PI;
    }

    inline bool checkAngleSync(double single_angle, double multi_angle) {
        return std::abs(single_angle - multi_angle) < 1;
    }
    inline double wrapAngle(double angle) {
        return fmod(angle, 360.0);
    }
} // end anon

Motor::Motor(uint8_t motorId, CANHandler& canRef, float reduction_ratio, float single_loop_max_ang_raw, float Nm_to_iq_m, float Nm_to_iq_b, float single_loop_ang_limit_low, float single_loop_ang_limit_high, float max_speed, float max_accel, float max_jerk, bool is_differential)
    : m_motorId(motorId), m_can(canRef), m_reduction_ratio(reduction_ratio), m_single_loop_max_ang_raw(single_loop_max_ang_raw), 
    m_Nm_to_iq_m(Nm_to_iq_m), m_Nm_to_iq_b(Nm_to_iq_b), 
    m_single_loop_ang_limit_low(single_loop_ang_limit_low), m_single_loop_ang_limit_high(single_loop_ang_limit_high), 
    m_max_speed(max_speed), m_max_accel(max_accel), m_max_jerk(max_jerk), m_is_differential(is_differential)
{
    // Clear state
    std::memset(&m_state, 0, sizeof(m_state));
}

//-------------------------------------------
//  Public Methods
//-------------------------------------------
const MotorState& Motor::getState() const
{
    return m_state;
}

void Motor::motorOff()
{
    sendCmd(0x80);
    readFrameForCommand(0x80);
}

void Motor::motorOn()
{
    sendCmd(0x88);
    readFrameForCommand(0x88);
}

void Motor::motorStop()
{
    sendCmd(0x81);
    readFrameForCommand(0x81);
}

void Motor::openLoopControl(int16_t powerControl)
{
    // Command 0xA0
    // data => [0x00,0x00,0x00,0x00, powerLo, powerHi, 0x00,0x00]
    std::vector<uint8_t> data(8, 0);
    pack16(data, 4, powerControl);

    sendCmd(0xA0, data);
    readFrameForCommand(0xA0);
}

void Motor::setTorque(int16_t iqControl)
{
    // 0xA1 => torque
    // data => [0x00,0x00,0x00, iqLo, iqHi, 0x00, 0x00, 0x00]
    std::vector<uint8_t> d(8, 0);
    pack16(d, 3, iqControl);

    sendCmd(0xA1, d);
    readFrameForCommand(0xA1);
}

void Motor::setSpeed(float speedControl)
{
    // 0xA2 => speed 
    // data => [0x00,0x00,0x00, speed0, speed1, speed2, speed3, 0x00]
    // convert speed to motors expected units (0.01 deg/s per LSB)
    speedControl = speedControl * 100;
    if (m_motorId == 6 || m_motorId == 7) {
        speedControl = speedControl * 10;
    } else {
        speedControl = speedControl * m_reduction_ratio;
    }
    int32_t speed_command = static_cast<int32_t>(speedControl);
    std::vector<uint8_t> d(8, 0);
    pack32(d, 3, speed_command);

    // std::cerr << "[Motor::setSpeed] speedControl: " << speedControl << std::endl;
    // std::cerr << "[Motor::setSpeed] speed_command: " << speed_command << std::endl;

    sendCmd(0xA2, d);
    readFrameForCommand(0xA2);
}

void Motor::setMultiAngle(int32_t angleControl)
{
    // 0xA3 => multi angle (1 frame)
    // data => [0x00,0x00,0x00, angle0, angle1, angle2, angle3, 0x00]
    int32_t clamped_angle = std::clamp(angleControl, static_cast<int32_t>(m_single_loop_ang_limit_low), static_cast<int32_t>(m_single_loop_ang_limit_high));
    int32_t scaled_angle = clamped_angle * 100 * m_reduction_ratio; // Scale to motor expectation
    std::vector<uint8_t> d(8, 0);
    pack32(d, 3, scaled_angle);

    sendCmd(0xA3, d);
    readFrameForCommand(0xA3);
}

void Motor::setMultiAngleWithSpeed(int32_t angle, uint16_t maxSpeed)
{
    // 0xA4 => angle + speed
    // data => [0x00, spdLo, spdHi, angle0, angle1, angle2, angle3]
    int32_t clamped_angle = std::clamp(angle, static_cast<int32_t>(m_single_loop_ang_limit_low), static_cast<int32_t>(m_single_loop_ang_limit_high));
    int32_t scaled_angle = clamped_angle * 100 * m_reduction_ratio; // Scale to motor expectation
    uint16_t scaled_speed = std::clamp(maxSpeed, static_cast<uint16_t>(0), static_cast<uint16_t>(m_max_speed*m_max_speed_modifier)) * ((m_motorId == 6 || m_motorId == 7) ? 10 : m_reduction_ratio);
    if (scaled_speed == 0) { scaled_speed = 1;}
    std::vector<uint8_t> d(7, 0);
    d[1] = static_cast<uint8_t>( scaled_speed & 0xFF );
    d[2] = static_cast<uint8_t>((scaled_speed >> 8) & 0xFF );
    pack32(d, 3, scaled_angle);
    //std::cerr << "[Motor::setMultiAngleWithSpeed] Input speed: " << maxSpeed << " | Scaled speed: " << scaled_speed << std::endl;
    //std::cerr << "[Motor::setMultiAngleWithSpeed] Input angle: " << angle << " | Scaled angle: " << scaled_angle << std::endl;

    sendCmd(0xA4, d);
    readFrameForCommand(0xA4);
}
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

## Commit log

2025-05-20 Initial Public Release: Armatron 7-DOF Robot Arm
    [1_base_link.stl, 2_shoulder_link.stl, 3_upper_brachium_link.stl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]
2025-05-23 add assembly step file
